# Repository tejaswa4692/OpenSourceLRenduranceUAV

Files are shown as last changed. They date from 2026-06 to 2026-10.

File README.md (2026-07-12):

# Long Range Endurance UAV

This is a long-endurance autonomous fixed-wing UAV designed for lightweight package delivery and remote logistics missions.

The project focuses on creating a low-cost, energy-efficient and open source aircraft capable of autonomous waypoint navigation, payload deployment, and extended flight durations using commercially available components and a custom-built airframe.

## Design Preview

### Airframe Concept

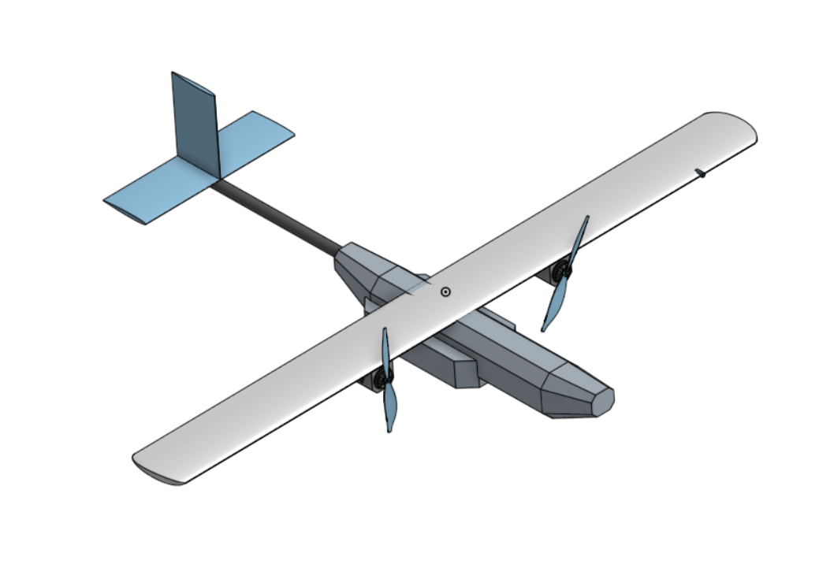
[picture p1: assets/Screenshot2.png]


### CFD simulations at 50kmph

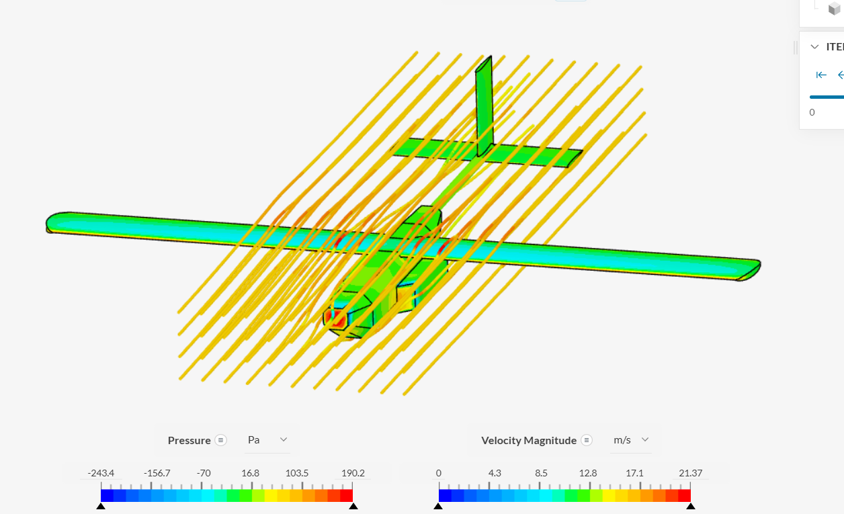
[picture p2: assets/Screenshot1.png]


### Wiring diagram

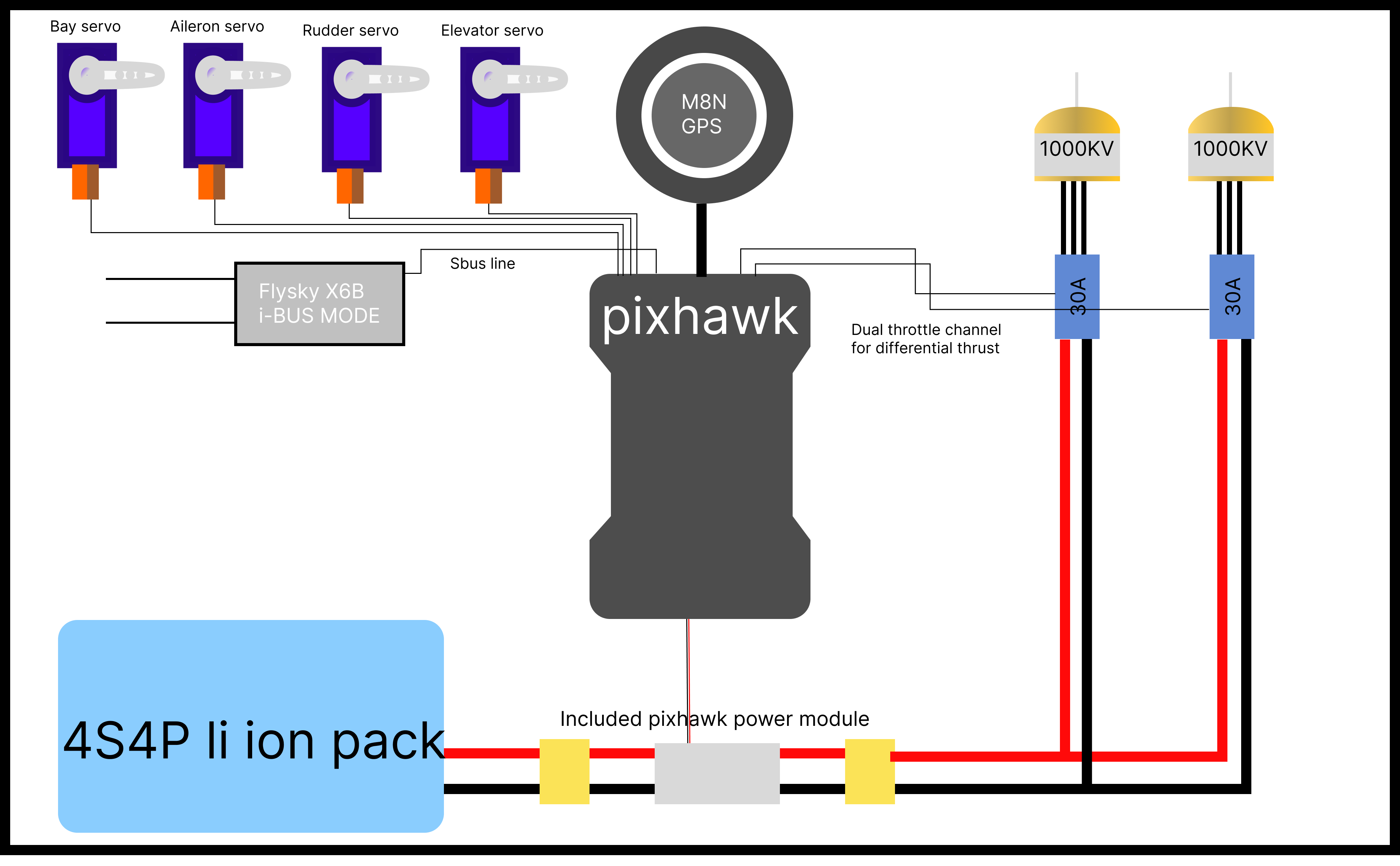
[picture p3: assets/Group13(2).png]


### CG location and mounting position for the electronics

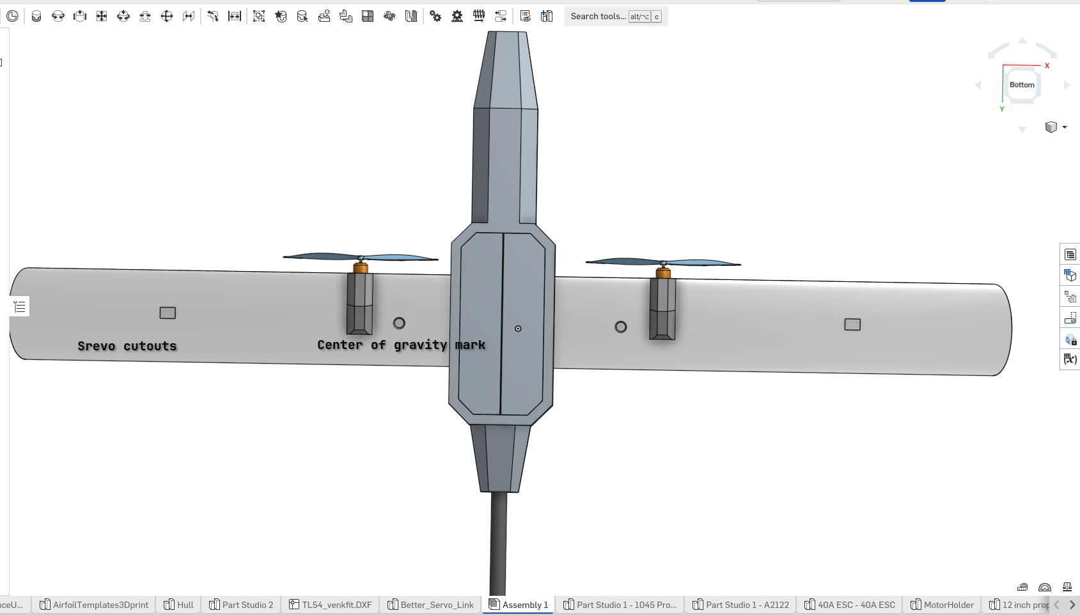
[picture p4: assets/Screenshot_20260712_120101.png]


### Pixhawk, Motor, Li Ion battery mounting for best structural integrity 

<table>
<tr>
<td>
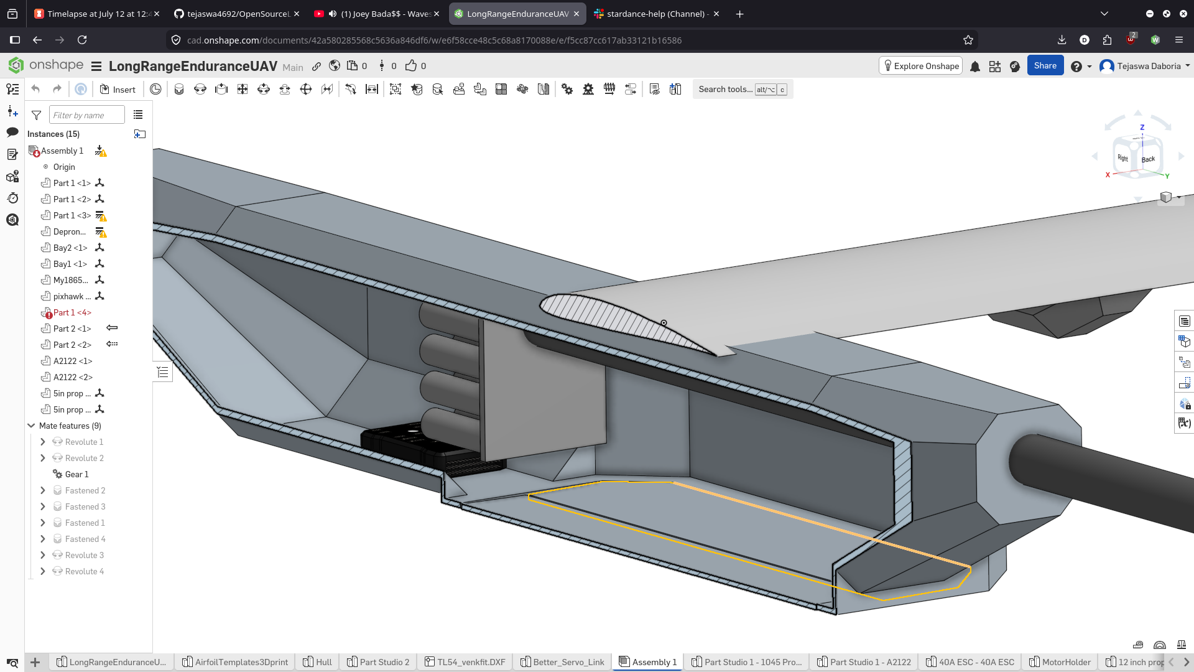
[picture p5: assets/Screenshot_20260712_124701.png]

</td>
<td>
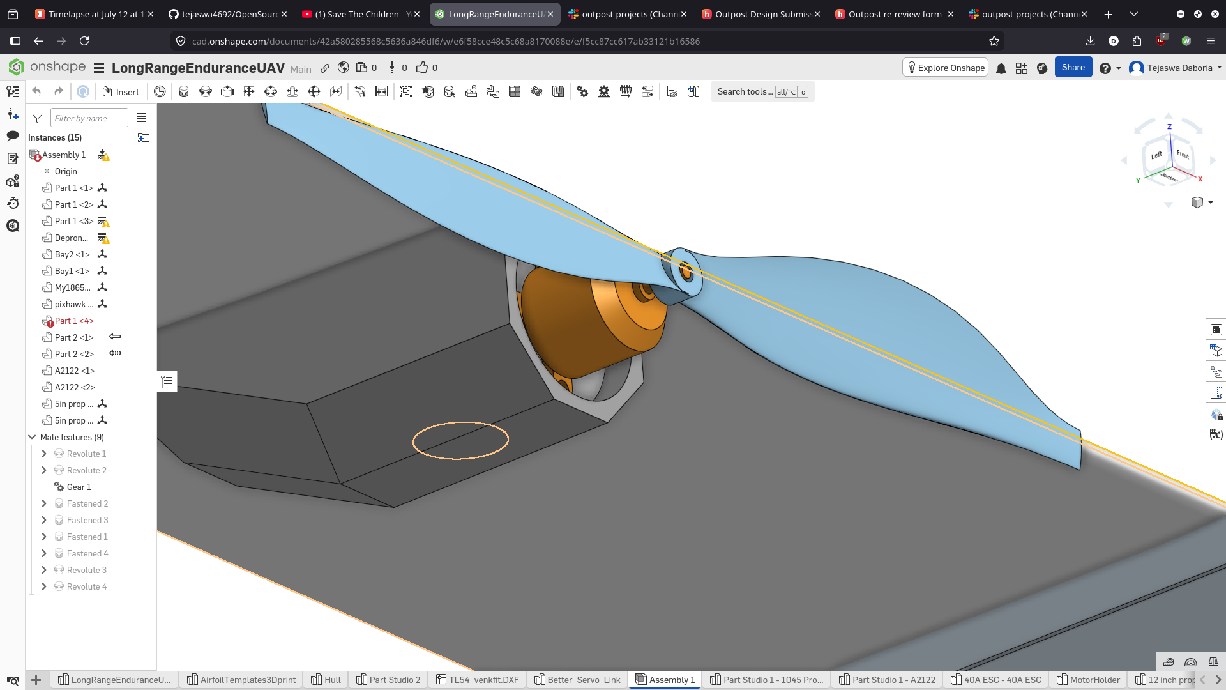
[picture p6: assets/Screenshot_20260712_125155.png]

</td>
</tr>
</table>

> [!NOTE]
> Location of GPS and Grabber servo will be added later take account of real life variables and strength of the motor.

## CAD Model

The complete CAD model is available on **[Onshape](https://cad.onshape.com/documents/42a580285568c5636a846df6/w/e6f58cce48c5c68a8170088e/e/f5cc87cc617ab33121b16586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)**.

## Key Features

* Autonomous flight using ArduPilot
* Pixhawk-based navigation and control
* Long-endurance Li-ion power system
* Lightweight foam-composite airframe
* Twin-motor propulsion system
* Payload delivery mechanism
* Modular and repairable design

## 3D prints
* Print out 1x rib template
* Print 1 AirfoilTemplates (not the one that has servo horns in it)
* Print out 1 Better_Servo_link.3mf file (it contains 8 control horns, way more than what we might need)
* Print 2 Motor mount plate

## Hardware

### Flight Control

* Pixhawk 2.4.8
* uBlox Neo M8N GPS + Compass

### Propulsion

* 2× A2212 1000KV Brushless Motors
* 2× 30A ESCs
* 10×4.5 Propellers

### Power System

* 4S4P (or more) 18650 Li-ion Battery Pack

## Status

The designing part is done, now i just have to wait if i qualify for the fund so that i can finally learn Pixhawk boards, then i can deliver the autopilot build process aswell

Ive made the BOM for this which is linked in the repo, the total budget just comes under $180 with some wiggle room which was my initial goal and im quiet happy by what im gonna be able to do with this money, on the day i made the BOM price of 1 dollar was 94.49 rupees.

## Wing build process

1. print the 3d printed templates in the CAD folder
2. put them over a piece of cardboard and cut them out
3. Use CA glue to reinforce the cardboard and stiffen it up
4. take a 18x45x3cm piece of thermocol and on the 18cm side place the 2 templates you just cut out with nails or pins
5. wrap nichrome wire around 2 nails with approx 50cm distance between them attach the power wires on nails and power it using a powersupply (i used my old laptops 19V 2.5A supply)
6. slowly cut out the 45cm wing section out of the thermocol, dont worry if u dont nail it first try
7. Repeat this 4 more times to get total wing length of 225cm
8. join all the wing pieces together as shown in the assembly
9. use the 2m furniture stick to use as a wingspar, hotglue it under the wing where the cavity for it is, make sure it fits flush with the wing, if it doesnt, edit the wing template to fit your spar, the step files for the wing templates have been provided
10. Now cut your paper bag in approx 22.5cm sections
11. Cover a part of your wing with the mixture of craft glue + water and then place your piece of paper over it, make sure there are no airbubbles under the wing, do this for all around the wing
12. cut strips of 5cm and place it on the seams of the paper you laid down before
13. wait for your wing to completely dry before moving on
14. cut out alerons from both sides and make them 60 x 5 cm from both sides, dont cut the alerons completely, leave some paper at top part where it can flex
15. cut a 50 degree chunk out of the aleron so it can go up and down
16. cut out a slot for your servo and place it in with hotglue(remember to center it beforehand)
17. twist the stainless steel wire to create a pushrod and attach the 3d printed better control horn on the aleron
18. put the pushrod wire through the assembly
19. cut a slit for the wire out and bring both wires to the middle (use jumper wires to extend the length of servo wires)
20. Put transpaarent packaging tape over your entire wing to smooth it out to reduce friction drag (optional)
21. Cut out motor mounts out of depron and 3d print the motormount plate aswell
22. attach them under the wing and route the wires to middle of the wing

Your wing is done it should look something like this 
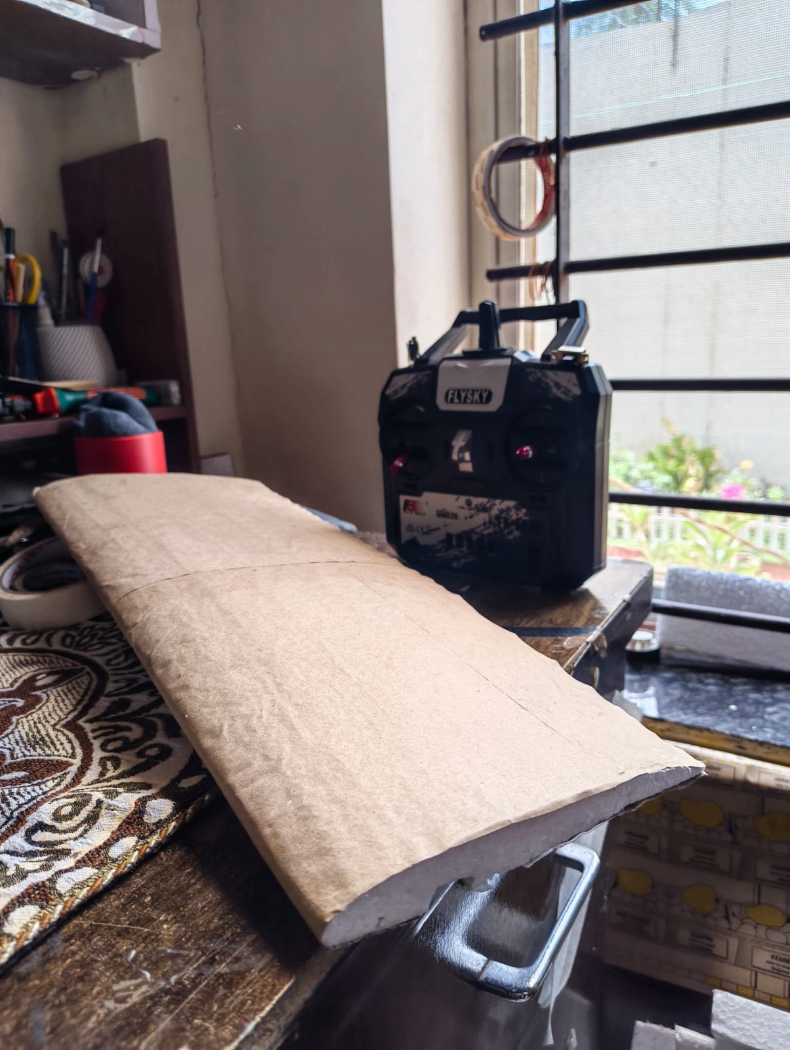
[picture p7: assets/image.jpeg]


#Fuselage build process
1. print out the fuselage templates
2. Use Depron sheets to cut out the fuselage templates (remember to cut out circles on top of it that fit the size of your wingspar
3. make a 60cm tube around the templates
4. make a simple nose ends for the tube that you just made for aerodynamics, you can experiment here by adding a canopy for fpv, your mind is the bottleneck here
5. Make a payload box out of depron as shwon in the image of the cad file, cut out the depron tube to fit that box rougly under the place of CG
6. before attaching, attach 2 servos inside the bay to open and close the door, wire these 2 servos together and leave it for now.
7. cut out a hatch from the top of the nose to acess the electronics inside later
8. Slide in the carbon spar from behind and hotglue it in place, make sure to leavev an inch free inside the fuselage
9. Put skewers through side of the fuselage to attach the wing

# Battery
Make the battery out of Li ion cells in a 4s4p configuration using spot welding, also solder the BMS to it for charging, and make sure to solder 2 XT 60 connectors to the ends of the battery (NOT THROUGH THE BMS!!!), use long zipties to attach the battery to the tailboom carbon rod

# elevons and rudder
1. cut out the smaller symmetric airfoil profile provided out of cardboard
2. follow the same procedure as you did to make the wings just make these 25cm long each
3. glue them in conventional tail configuration along the carbon spar and route the servo wires through the carbon spar to the fuselage

Your aircraft frame is ready to fly, go out and test it out before adding autopilot to it

A video explaining the build process will also be coming soon 

# Autopilot
Coming soon......

Files can also be found on printables here
https://www.printables.com/model/1756593-long-range-endurance-uav

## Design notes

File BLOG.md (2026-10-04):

# Epic UAV crash blog

So lets start with what happend
I took the 1m prototype out to fly, which is a reliable platform i can experiment upon, and if it crashes i know nothing will happen
I was doing its first flight with the pixhawk (non autonomous) and i was doing the ardupilot autotune sequence, thats why in video before the mount breaks it looks like that the plane is wobbling

Its just me moving the sticks you have to do it to tune the PIDs 

So after like 1:20 mins of flying the aircraft suddently dips, i thought it was the prop that came off, I had control so i tried to land it as best as i can

After retrieving the aircraft it was a lot worse than i thought, the heat from the motor melted the PLA mount (i didnt have any other filament and from my past experience i never had this happen to me before) and the screws that were in the motor just slid clean off the holes, Now we COULD blame the filament and the fact that i made it too thin, but i think theres something way more important we might miss

These cheap BLDC use countersink M3 screws to fasten themselves, And this motor produces peak thrust of roughly 1KG stationary, So when i was flying the countersink chamfer of the screw acted like 
a wedge placed in wood, and the force from the motor going up and down (due to autotune) was like a hammer hitting it from the back
Hence, it came loose and fell in the field below

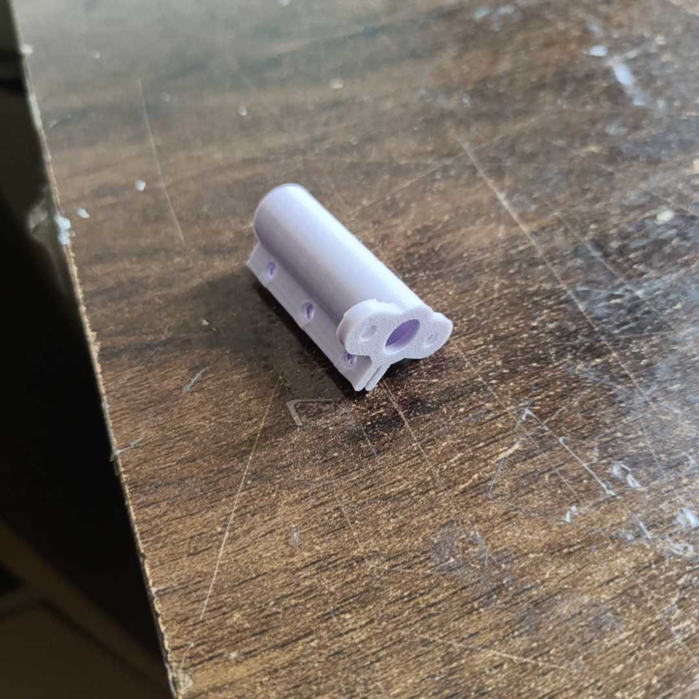
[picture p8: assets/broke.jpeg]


# How i fixed it

For starters i made the mount MUCH thicker and used 100% infill this time

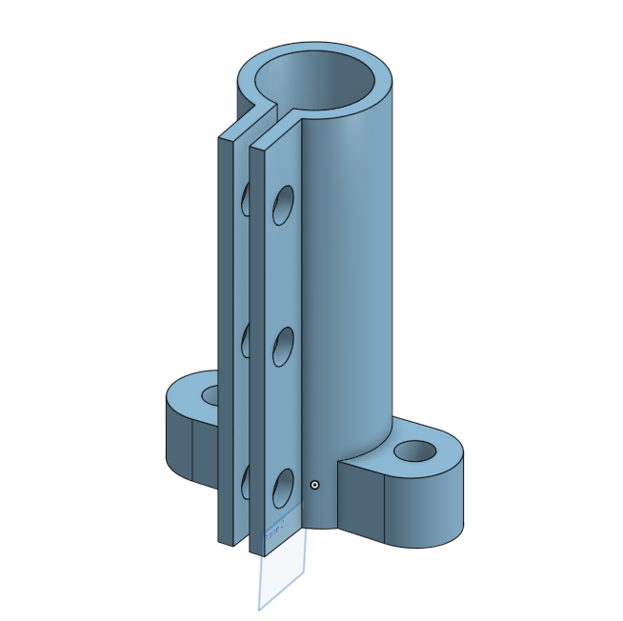
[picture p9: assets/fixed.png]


And instead of coutnersink screws i used my own M3x6 hex screws (that have a flat base) with washers to dissipate more heat while flying

It has seemed to serve me well as i did test this one with a spare motor i repurposed from other plane i had lying around, and it did seem to have a successful flight

Heres the link to the youtube video (its a lil embarrassing dont judge) 

https://youtu.be/xHYlskcMfM4

# What precautions i took

This time i had like 3 zipties holding down the 3 phase wires of motor like SUPER tightly to the tube so IF the motor comes off the worst that can happen is that the motor just comes off the mount and keeps dangling on the tube

https://stardance.hackclub.com/projects/12767/devlogs/63215

This is the link of the devlog from when i flew with those precautions 

# What needs replacing

Due to me being a shit pilot and crashing a lot, i have started making frames and wings that are SUPER crash resistant (like literally it fell from 100m and not even a scratch on it) 

https://robu.in/product/a2212-10t-13t-1000kv-brushless-motor-with-soldered-connector/
This is the motor id need (the exact same kind) it costs 464 (including shipping) which is 5 dollars at the time im writing this 

https://stardance.hackclub.com/projects/12767/devlogs/63148

This is link to the devlog when the motor came off, for some reason the video quality on stardance is much better than that of youtube

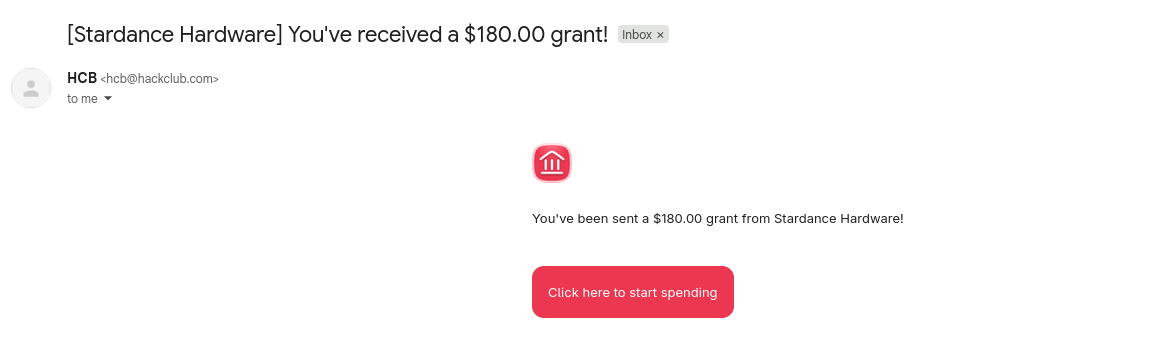
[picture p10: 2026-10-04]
assets/Screenshot_20260713_125502.png

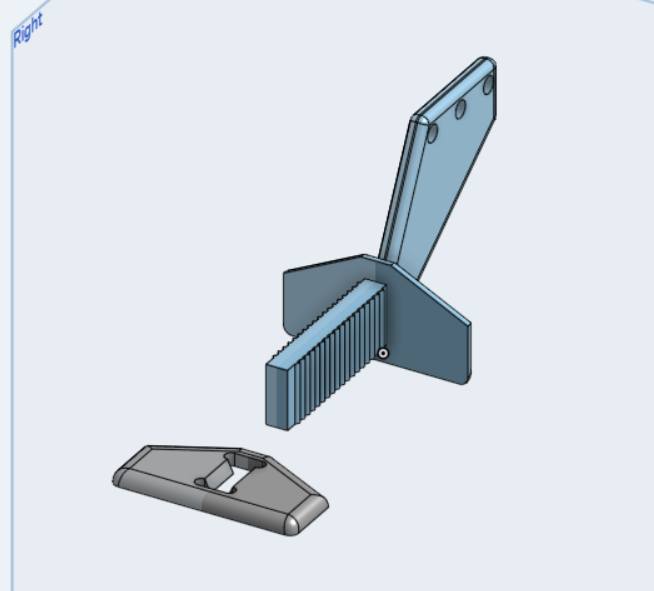
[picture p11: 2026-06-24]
assets/Opera Snapshot_2026-06-24_115818_cad.onshape.com.png

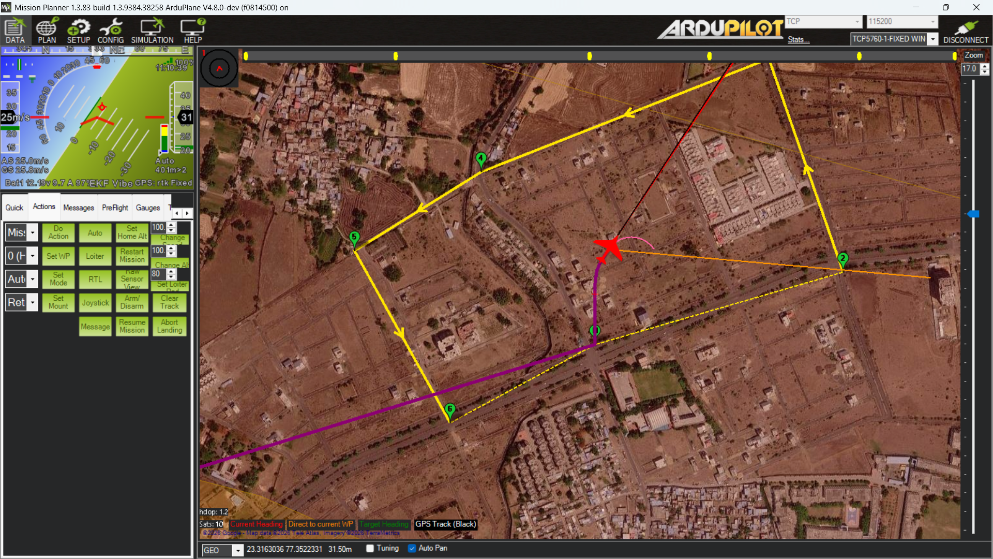
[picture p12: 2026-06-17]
assets/Screenshot (269).png

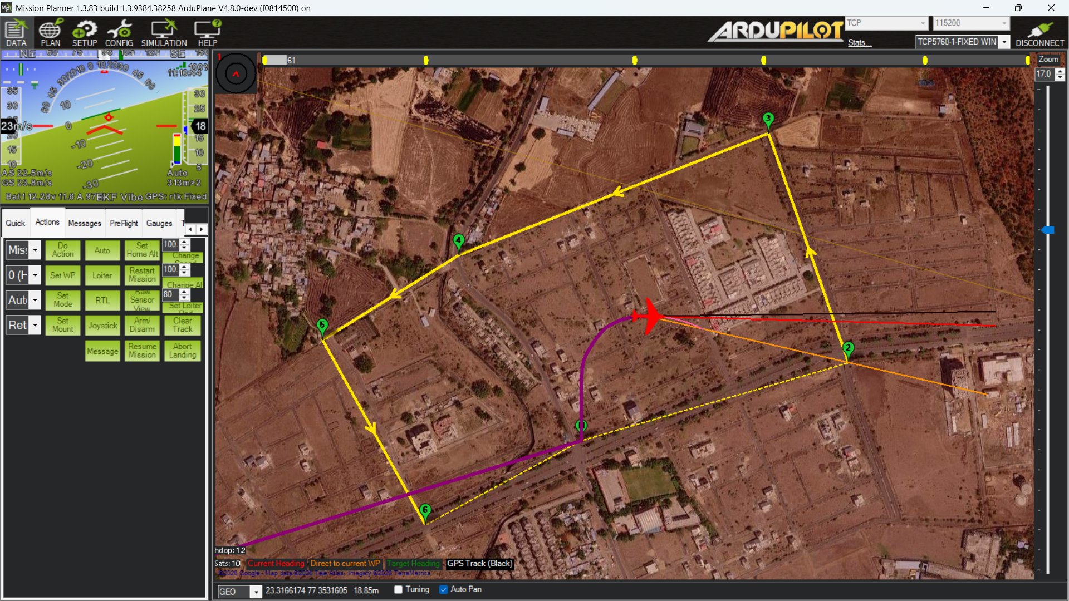
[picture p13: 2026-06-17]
assets/Screenshot9.png

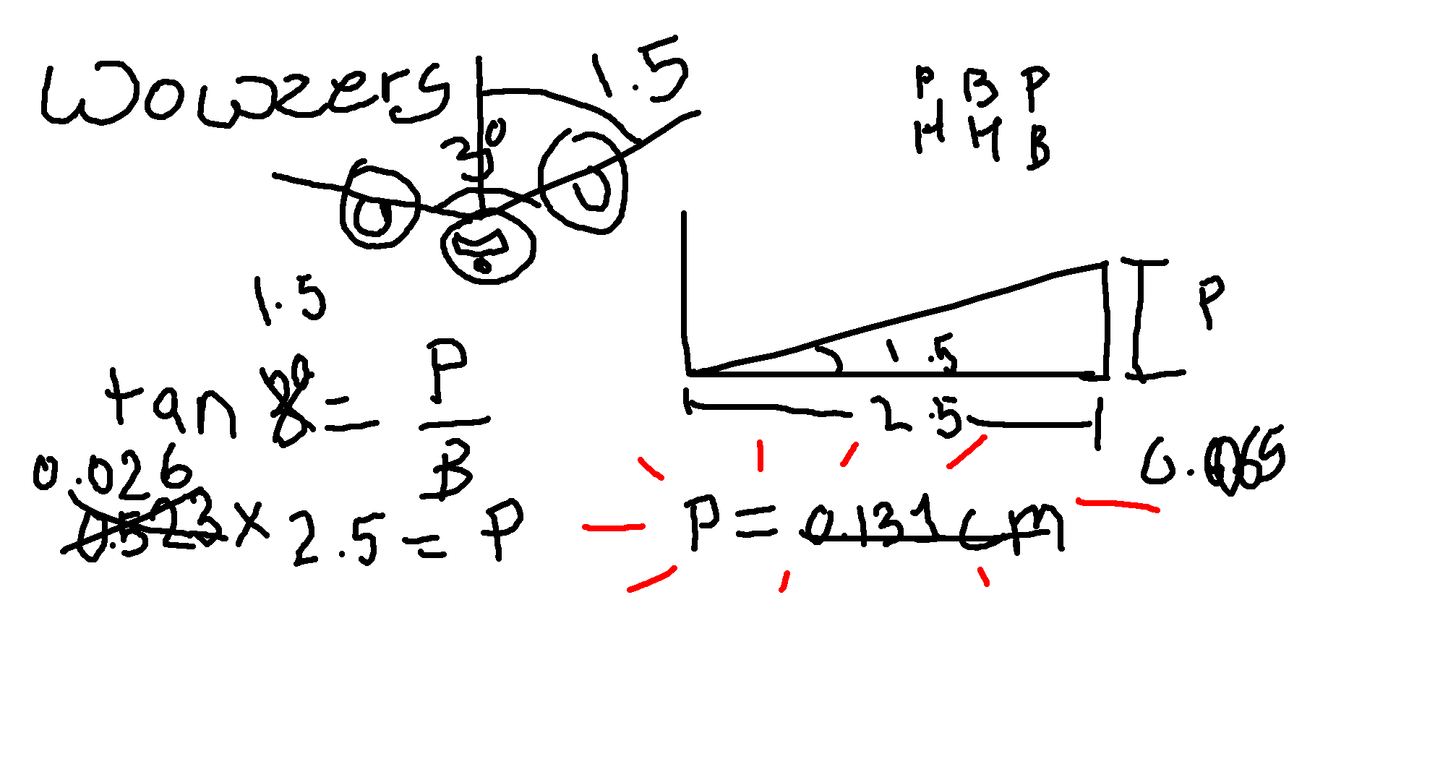
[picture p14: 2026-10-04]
assets/wowozers.png

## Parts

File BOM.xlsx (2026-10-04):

Item Name | Qty | Price (total) (USD) | Item link | Notes
A2212 1000KV BLDC | 2 | $6.67 | https://quartzcomponents.com/products/a2212-1000kv-bldc-drone-motor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 | Twin-motor propulsion system selected to provide redundancy and improved reliability for autonomous delivery missions. The motors operate well below maximum power during cruise, improving efficiency and reducing thermal stress. | done
30A ESC | 2 | $12.20 | https://evelta.com/2-6s-30a-bidirectional-self-starting-esc-speed-controller-model-a-b-c-d/ | Great 30A ESC wont even be pushed to max as one motor just consumes 14A at peak load, best part they support 2s-6s | done
180 degree Metal gear servos for control surface actuation and payload bay | 2 | $10.00 | https://robocraze.com/products/mg90s-servo-motor?variant=40192707297433 | good quality servos that have nice torque and life, 2 for alerons, 2 for flaps, 1 for elevator, 1 for rudder and 2 for the bay | done
Pixhawk 2.4.8 | 1 | $63.50 | https://robu.in/product/pixhawk-px4-autopilot-pix-2-4-8-32-bit-flight-controller/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 | PixHawk running ardupilot is the best choice with keeping the budget constraints in mind, and most UAV enthusiasts already have this or even better FC on them already
EPS foamboard | 5 | $2.00 | local shop | Cheap foamboard, quiet flimsy as it is alone, but with my wing manufacturing process, works perfectly
Carbon spar 1m | 1 | $19.91 | https://www.vortex-rc.com/product/15x13x1000mm-3k-cf-tube-carbon-fiber-fibre-tube-3k-roll-wrapped/ | a carbon rod to make the tail boom out of to reduce massive CG tweaking while flying the aircraft | done
18650 3000mah cells | 20 | $12.65 | https://quartzcomponents.com/products/18650-li-ion-3-7v-3000mah-rechargeable-battery-winwaycopy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 | Cheap cells will do as well be making a big battery, C rating of these cells is 1-3 so If I make a 15000Ah Battery ill be good to go | done
1045 props | 3 | $1.59 | https://quartzcomponents.com/products/1045-drone-propeller-blade-set-cw-and-ccw-pair?variant=33096741224583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 | A set comes with 2 prop, these are cheap props so buying 3 is a no brainer | done
XT60 connector | 2 | $0.55 | https://quartzcomponents.com/products/xt60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 | For the battery | done
BMS for 4s | 1 | $1.29 | https://quartzcomponents.com/products/4s-high-current-up-to-30a-lithium-battery-protection-board-14-8v-16-8v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 | A battery managemement module to avoid overcharging or discharging and balanced charging | done
14AWG wire | 1 | $0.93 | https://quartzcomponents.com/products/14awg-silicone-wire-red-1-meter-high-quality-ultra-flexible-for-battery-packs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 | 14 AWG so wires don’t heaat up | done
Nickel Strips 1m | 2 | $0.32 | https://quartzcomponents.com/products/6mm-x-0-12mm-nickel-coated-strip-for-18650-cells-1-meter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 | nickel strips to spot weld the batterypack | done
rPLA filament (20-30g) | 1 | $0.40 | a spool of flament lying on your floor with barely any left on it | To make the templates for wing and to make ribs for the fuselage
Cheap stainless steel wire | 1 | $4.00 | local shop | For servo linkages
Neo M8N GPS | 1 | 21.73 | https://robu.in/product/neo-m8n-gps-module-with-compass-for-apm-with-extra-connector-for-pixhawk/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 | A good quality GPS which has proved itself in the community and is reliable for completely autonomous flights | done got m7n instead
Pixhawk power module | 1 | $4.96 | https://robu.in/product/apm-pixhawk-power-module-output-bec-3a-xt60-connector-28v-90a/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 | Just a power module for the pixhawk | done
stick used for lining furnitures | 1 | $0.42 | local shop | a stick, very cheap, a bit on the heavier side but will do
Paper bags | 8 | $0.00 | Recycle | recycled paper bags in which you buy your grocery, or any kind of packaging paper will do
Adhesives | 1 | $3.00 | local shop | CA glue + 2 part epoxy + hotglue
Jumper cables (M-F) | 1 | $0.44 | https://robu.in/product/male-to-female-jumper-wires-40-pcs-10cm/?gad_source=1&gad_campaignid=17427802559 | Male to female jumper cables
Jumper cables (F-F) | 1 | $0.42 | https://robu.in/product/10cm-female-female-breadboard-jumper-dupont-2-54mm-1p-1p-cable-40-pcs/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 | Female to female jumper cables
Flysky x6b reciever | 1 | $9.89 | https://robu.in/product/x6b-2-4g-6ch-bus-ppm-pwm-receiver-afhds/ | A flysky reciever to land the aircraft once the mission ends | done
Zip Ties, Heat Shrink, Connectors, Nichrome wire | 1 | $0.50 | local shop
Total Price (USD): | 177.37

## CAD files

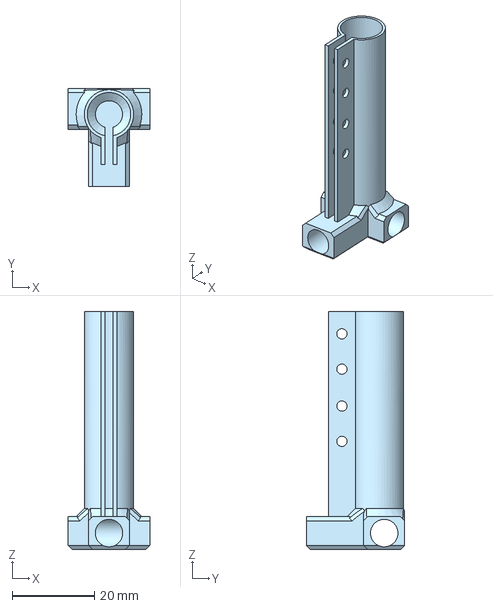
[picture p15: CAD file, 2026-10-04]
cad/RearStabWingSparConnector(1).step
20.0 x 24.0 x 58.0 mm

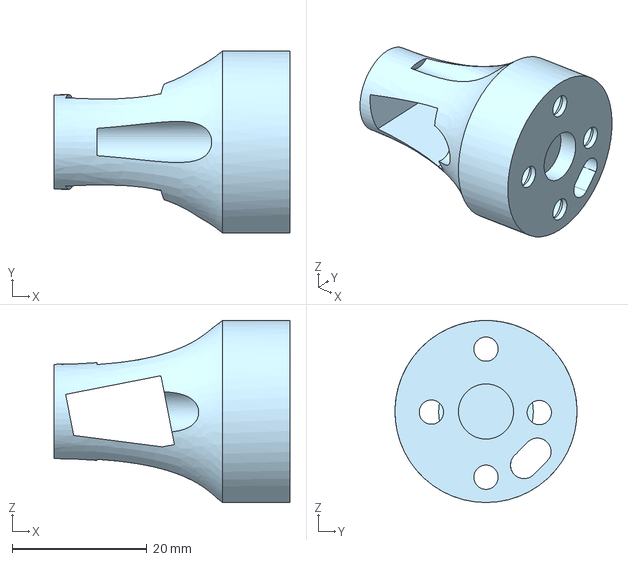
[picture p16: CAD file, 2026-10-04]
cad/BLDCMotorMount.step
35.0 x 27.0 x 27.0 mm

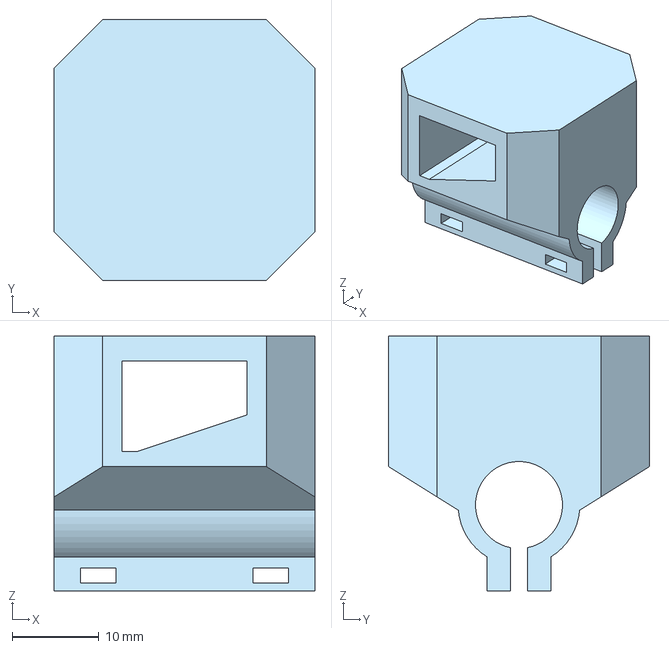
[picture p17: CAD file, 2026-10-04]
cad/WingSparHolder(3).step
30.0 x 30.0 x 29.3 mm

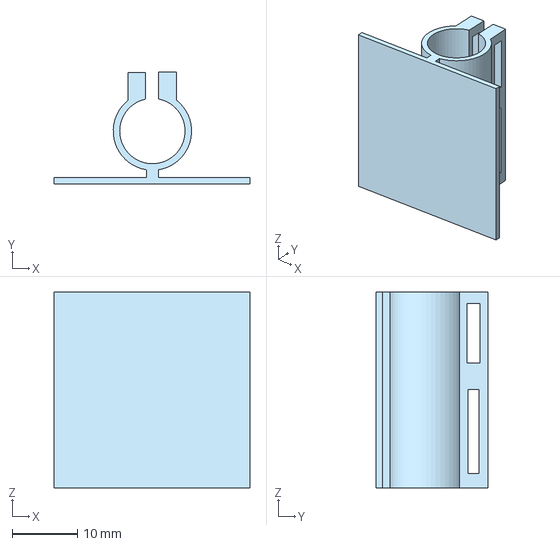
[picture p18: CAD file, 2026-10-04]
cad/SimpliFLyTelemetry.step
30.0 x 17.1 x 30.0 mm

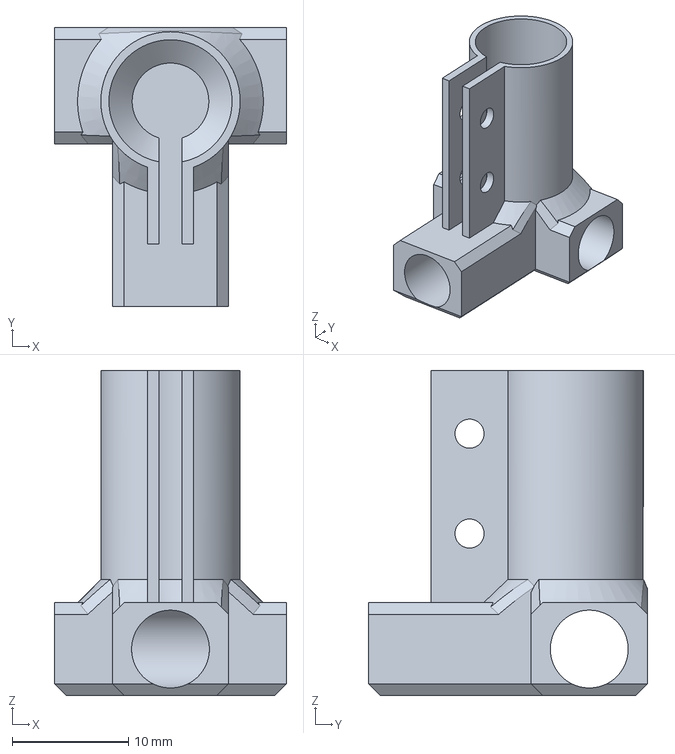
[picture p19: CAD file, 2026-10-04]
cad/RearStabWingSparConnector.3mf
20.0 x 24.0 x 28.0 mm

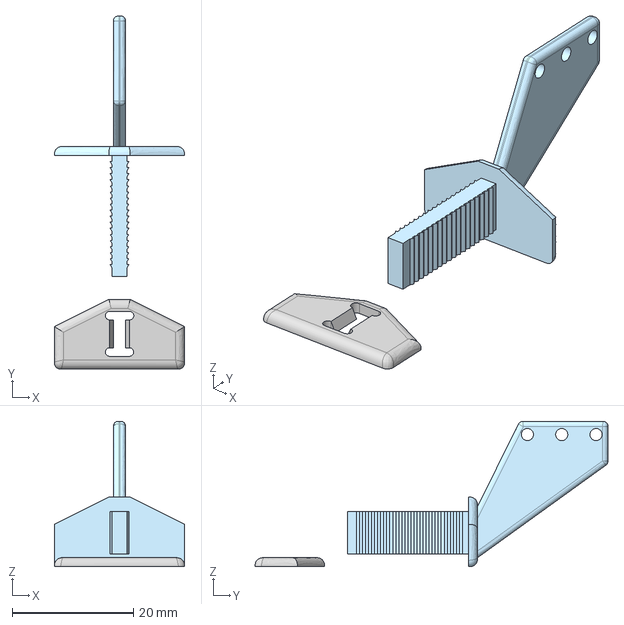
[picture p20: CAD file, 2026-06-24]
cad/Better_Servo_Link.step
21.5 x 58.2 x 24.0 mm

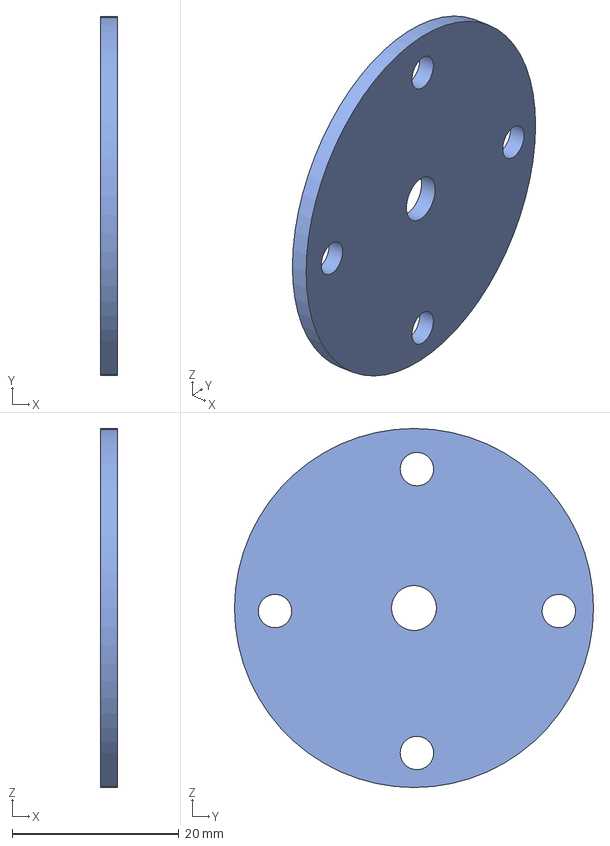
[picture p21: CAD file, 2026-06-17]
cad/MotorMountPlate.step
2.00 x 43.0 x 43.0 mm

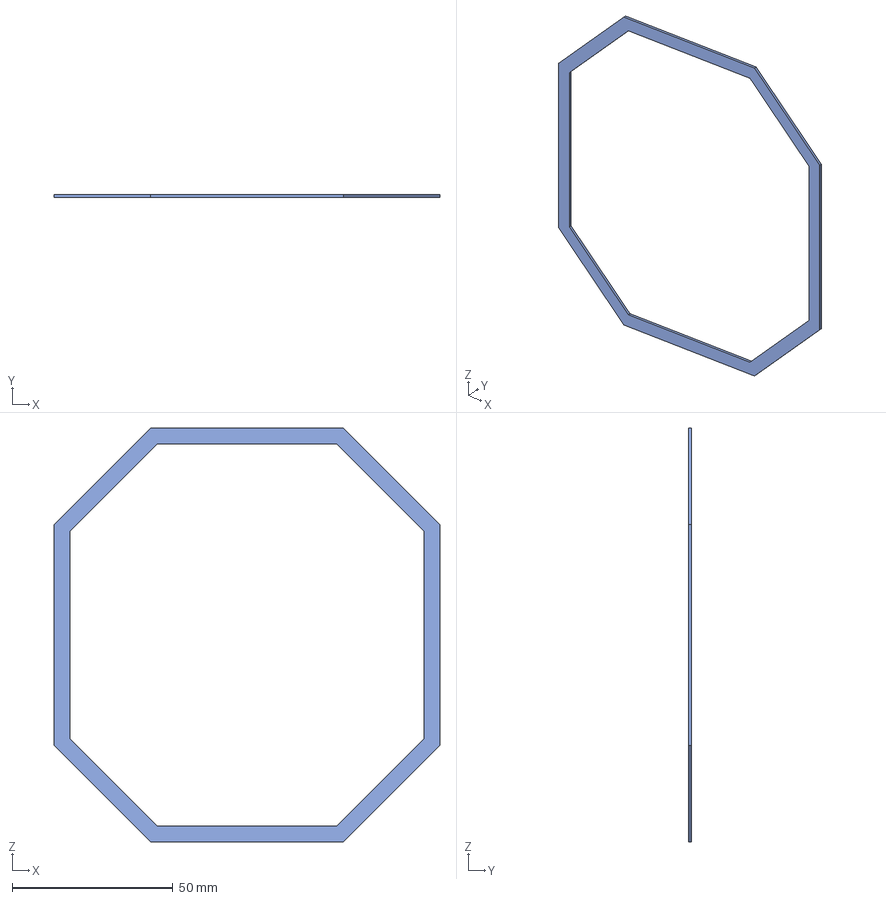
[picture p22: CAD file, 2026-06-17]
cad/Aircraft-Rib-Template.step
120.0 x 1.00 x 128.7 mm

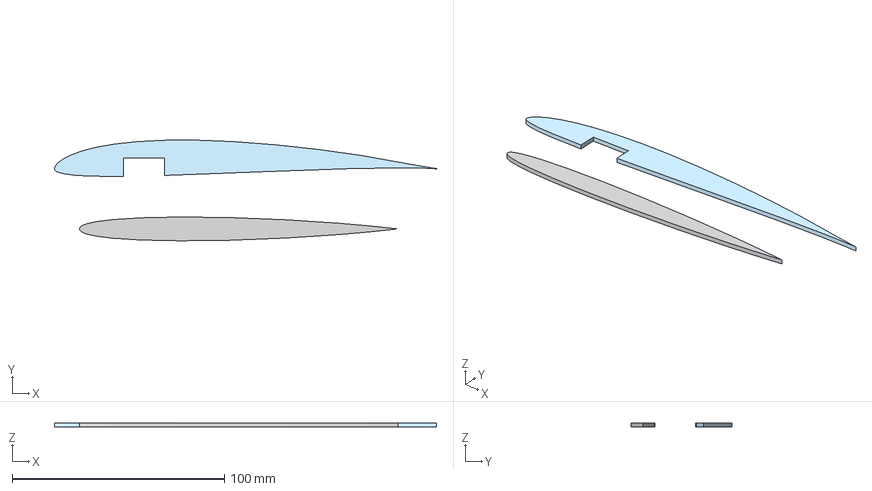
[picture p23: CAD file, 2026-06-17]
cad/AirfoilTemplates3Dprint.step
180.0 x 47.4 x 2.00 mm

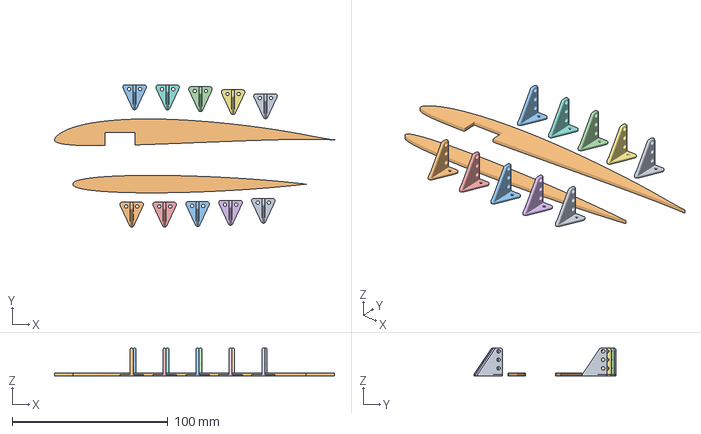
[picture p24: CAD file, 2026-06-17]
cad/AirfoilTemplates+ServoHorns.3mf
180.0 x 91.5 x 18.0 mm
ServoLinkage x 10
AirfoilTemplates3Dprint

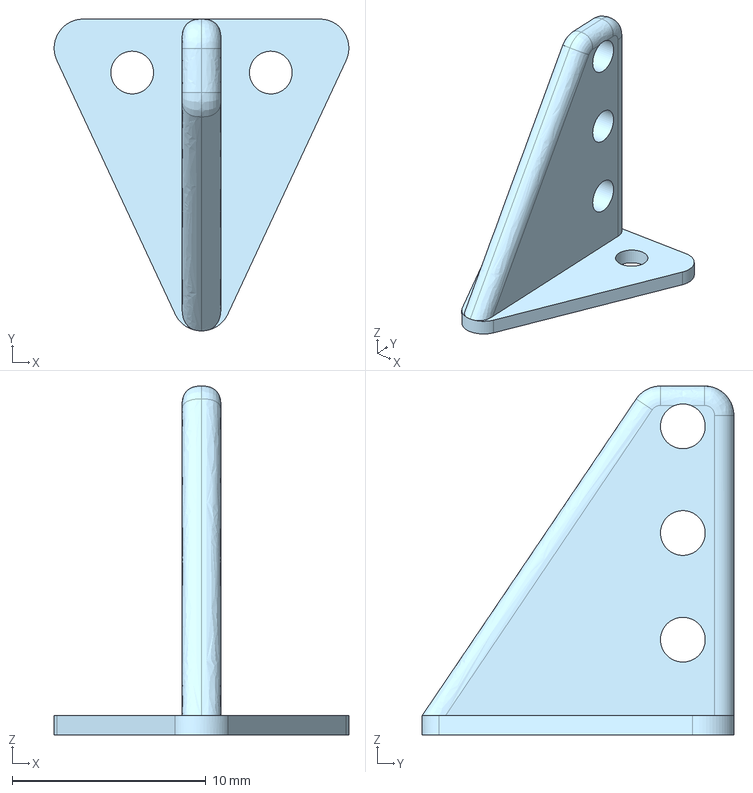
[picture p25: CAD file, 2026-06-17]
cad/ServoLinkage.step
15.2 x 16.1 x 18.0 mm

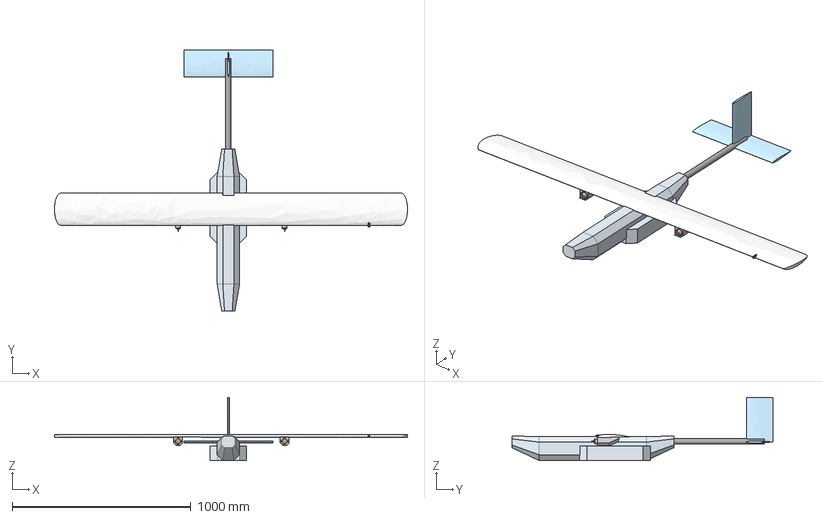
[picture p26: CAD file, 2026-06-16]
cad/UAVwMotorsV2.step
1975.0 x 1461.6 x 354.7 mm
A2122 x 2
Bay1
My18650
pixhawk
Bay2
DepronHull

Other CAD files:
cad/RibTemplate.3mf
cad/MotorMountPlate.3mf

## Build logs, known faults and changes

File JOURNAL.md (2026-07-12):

# Project Journal

## June 15, 2026

* Thought of a sub 500g flying wing aircraft for this job
* Selected fixed-wing configuration for its excellent performance.
* thought about the bay dropping idea and researched upon it to how to achive it using a flightcomputer
* Evaluated multiple airfoils and wing geometries.
* Calculated wing loading and estimated flight performance for the flying wing.
Time: 3 hours

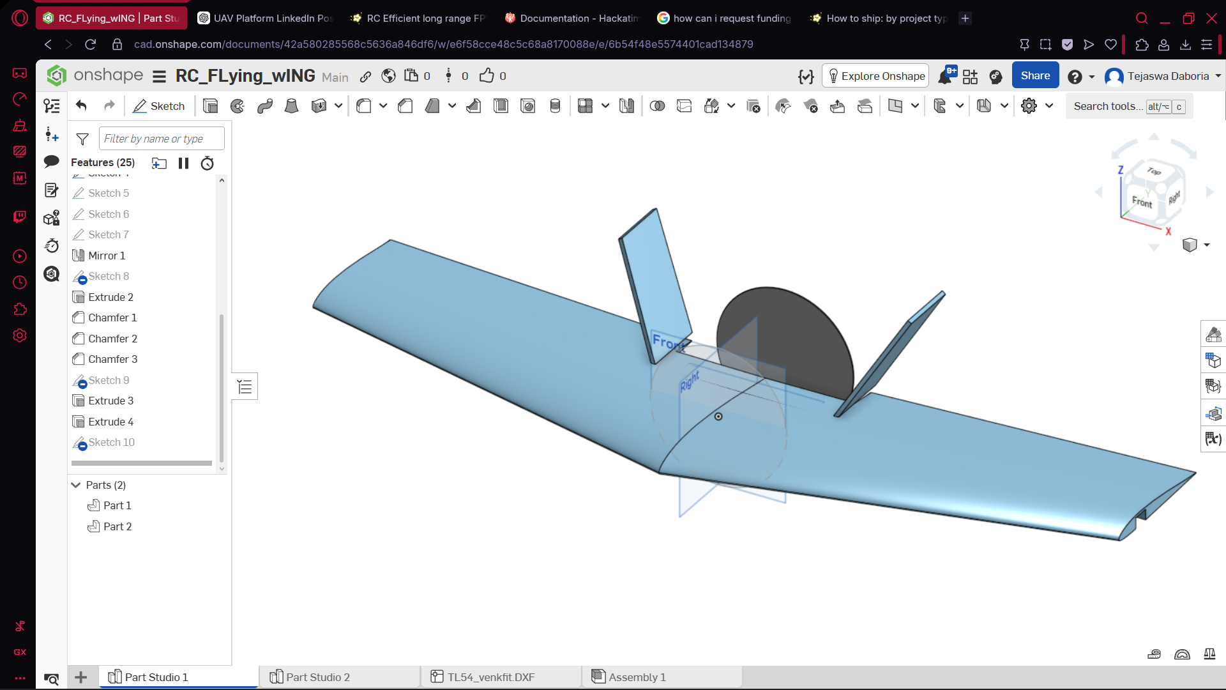
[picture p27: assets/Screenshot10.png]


## June 16, 2026

* Changed the whole design into a 2m wingspan large UAV aircraft to maximise stablity
* Decided upon the battery pack
* Thought of using 1 5010 bldc for the propulsion system
* picked SD7037 airfoil for its efficient long range UAV characterstics and low reynolds number providing excellent lift and stablity
* learned to setup CFD sims and ran multiple on the airframe to test its capablities
* Found the respective electronics that i would need to make this project possible and made a BOM, turns out i am going overbudget to 200 dollars
* Canged to cheaper 2 A2212 BLDC motors with 10 inch props and removed telemetry as its not that necessary, finally was able to get the plane underbudget also gave up on using a carbon spar for wing and instead i using a wooden spar
* Did some math to figure out flight times, would need to make it in real life to map out how long can it actually go to
* installed mission planner to get a fell of things, turns out this is a bit complex

Time: 5 hours



## June 17, 2026

* Made some more tiny changes in the BOM trying to get even more underbudget
* Cut out an SD7037 airfoil out of thermocol to test outside in my dads car to get some data to plot into mission planner about the stall characterstics
* learned mission planner and was fianlly able to plan my first mission and i ran it in a simulator and it worked as intended
* Made the control horn, motor mount and templates for wing and fuselage rib profiles
* Cleaned up the github repo and added my sacred build process to the Readme
* Cleaned up the BOM and finalised the part list.
* Went over everything again to get everything ready for submission
* Made the JOURNAL.md file

Time: 5 hours



## July 12, 2026

* Made the wiring diagram in figma and added it to the readme as the outpost submission required it
* Added images for locations for mounting the electronics




Time: 1 Hour

## Total Time

14 hours

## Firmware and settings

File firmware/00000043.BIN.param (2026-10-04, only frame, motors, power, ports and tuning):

BATT_AMP_OFFSET,0
BATT_AMP_PERVLT,36.364
BATT_ARM_MAH,0
BATT_ARM_VOLT,0
BATT_CAPACITY,1500
BATT_CRT_MAH,0
BATT_CRT_VOLT,0
BATT_CURR_PIN,3
BATT_FS_CRT_ACT,0
BATT_FS_LOW_ACT,0
BATT_FS_VOLTSRC,0
BATT_LOW_MAH,0
BATT_LOW_TIMER,10
BATT_LOW_VOLT,0
BATT_MONITOR,4
BATT_OPTIONS,0
BATT_SERIAL_NUM,-1
BATT_VLT_OFFSET,0
BATT_VOLT_MULT,10.858
BATT_VOLT_PIN,2
BATT_WATT_MAX,0
BATT2_MONITOR,0
BATT3_MONITOR,0
BATT4_MONITOR,0
BATT5_MONITOR,0
BATT6_MONITOR,0
BATT7_MONITOR,0
BATT8_MONITOR,0
BATT9_MONITOR,0
FLTMODE_CH,5
FLTMODE_GCSBLOCK,0
FLTMODE1,5
FLTMODE2,13
FLTMODE3,5
FLTMODE4,5
FLTMODE5,5
FLTMODE6,8
INS_GYRO_FILTER,20
INS_HNTCH_ENABLE,0
SERIAL0_BAUD,115
SERIAL0_PROTOCOL,2
SERIAL1_BAUD,57
SERIAL1_OPTIONS,0
SERIAL1_PROTOCOL,2
SERIAL2_BAUD,57
SERIAL2_OPTIONS,0
SERIAL2_PROTOCOL,2
SERIAL3_BAUD,230
SERIAL3_OPTIONS,0
SERIAL3_PROTOCOL,5
SERIAL4_BAUD,230
SERIAL4_OPTIONS,0
SERIAL4_PROTOCOL,5
SERIAL5_BAUD,57
SERIAL5_OPTIONS,0
SERIAL5_PROTOCOL,-1
SERVO1_FUNCTION,78
SERVO1_MAX,2000
SERVO1_MIN,1500
SERVO1_REVERSED,1
SERVO1_TRIM,1750
SERVO2_FUNCTION,4
SERVO2_MAX,2000
SERVO2_MIN,1000
SERVO2_REVERSED,1
SERVO2_TRIM,1500
SERVO3_FUNCTION,70
SERVO3_MAX,2000
SERVO3_MIN,1000
SERVO3_REVERSED,0
SERVO3_TRIM,1000
SERVO4_FUNCTION,0
SERVO4_MAX,2000
SERVO4_MIN,1000
SERVO4_REVERSED,0
SERVO4_TRIM,1000
SERVO5_FUNCTION,21
SERVO5_MAX,2000
SERVO5_MIN,1000
SERVO5_REVERSED,0
SERVO5_TRIM,1500
SERVO6_FUNCTION,19
SERVO6_MAX,2000
SERVO6_MIN,1000
SERVO6_REVERSED,1
SERVO6_TRIM,1500
SERVO7_FUNCTION,21
SERVO7_MAX,1900
SERVO7_MIN,1100
SERVO7_REVERSED,0
SERVO7_TRIM,1500
SERVO8_FUNCTION,77
SERVO8_MAX,1700
SERVO8_MIN,1000
SERVO8_REVERSED,0
SERVO8_TRIM,1370
SERVO9_FUNCTION,0
SERVO9_MAX,1900
SERVO9_MIN,1100
SERVO9_REVERSED,0
SERVO9_TRIM,1500

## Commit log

2026-06-16 Initialize README with project overview and details
    Added detailed project description, key features, hardware specifications, and current status for the Long Range Endurance UAV.
2026-06-16 oopsy daisy, gotta switch the numbers of screenshot
    Reformatted the README to improve structure and clarity, including image placements and feature descriptions.
2026-06-17 changed BOM
    [BOM.xlsx]
2026-06-17 BOM changes and added 3d printed parts
    [Aircraft-Rib-Template.step, AirfoilTemplates+ServoHorns.3mf, AirfoilTemplates3Dprint.step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]
2026-06-17 minor change
    [BOM.xlsx]
2026-06-17 Added build directions for the wing
2026-06-17 added a csv too
    [BOM-CSV.csv, BOM.xlsx]
2026-06-24 added a better servo link
    [BOM.xlsx, Better_Servo_Link.step]
2026-07-12 added images
    [BOM-CSV.csv]
2026-07-12 Update README with new diagrams and build instruction
    Added wiring diagram, CG location, and mounting positions for electronics. Updated build processes for wing and fuselage.
2026-07-12 Revise README with CAD model and project updates
    Added CAD model link and updated project details.
2026-07-12 Update JOURNAL.md with July 12 entries
    Added new entries for July 12, 2026, including wiring diagram and images for electronics mounting locations.
2026-10-04 added broken and fixed images
    [00000043.BIN.param, 00000043.log.param, BLDCMotorMount.step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]
2026-11-07 added wiring diagram
2026-11-07 updated BOM
